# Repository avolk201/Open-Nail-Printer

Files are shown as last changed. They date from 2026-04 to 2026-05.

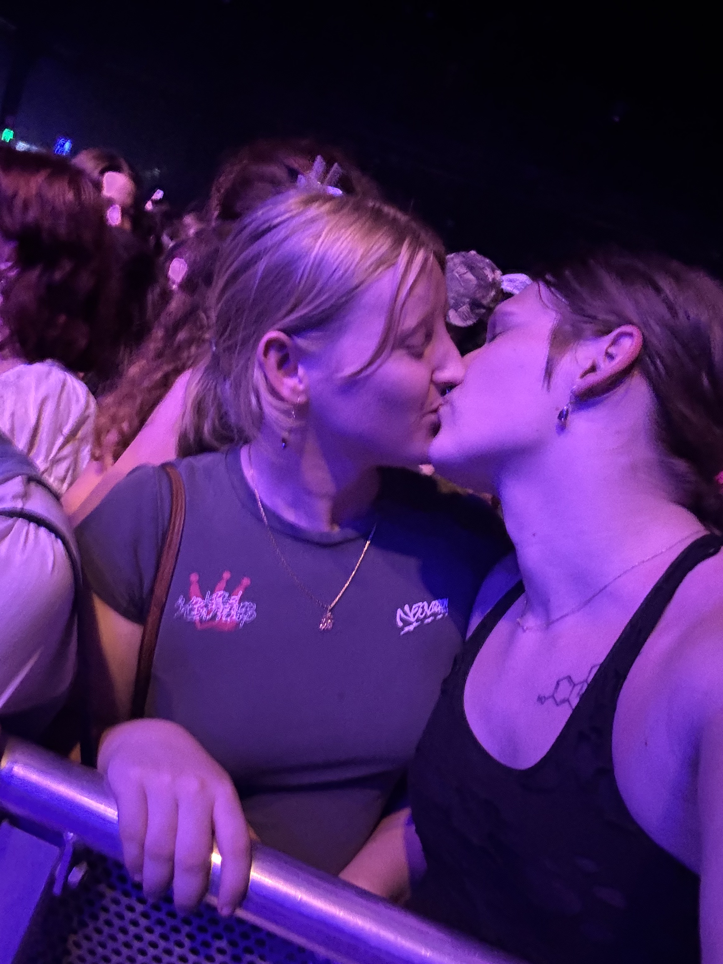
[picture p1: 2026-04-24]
backend/uploads/ethel cain.jpeg

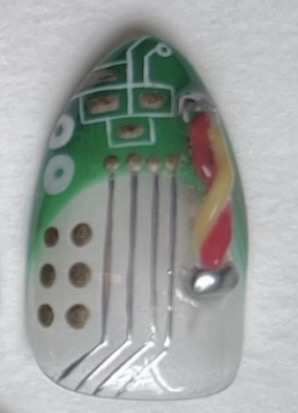
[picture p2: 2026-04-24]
backend/uploads/IMG_1966.jpeg

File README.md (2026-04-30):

# Open-Source Inkjet Nail Printer

## Overview
This repository contains the hardware schematics, firmware, and software required to build a custom, desktop-scale inkjet nail printer. The system utilizes a standard thermal inkjet (TIJ) cartridge (HP 63) to deposit water-based cosmetic/edible ink directly onto a prepared human nail. 

Unlike commercial alternatives that rely on closed-source hardware and DRM-locked consumables, this project provides a fully open architecture. It uses a distributed processing model, offloading high-level computer vision and web serving to a Raspberry Pi, while delegating strict, microsecond-accurate hardware control to an ESP32 microcontroller utilizing I2S Direct Memory Access (DMA).

## System Architecture

The project is divided into three distinct operational domains:

### 1. High-Level Processing (Raspberry Pi 3B+)
* **Environment:** Python 3, FastAPI, OpenCV.
* **Function:** Operates in a headless kiosk mode serving a React/Vue frontend to a local touchscreen UI. 
* **Vision Pipeline:** Captures the finger via a fixed-focus, low-distortion downward-facing camera. Allows the user to define a bounding box, warps the selected 2D image using a 1D sine-wave pre-distortion algorithm to map to the nail's curvature, and converts the RGB image into a binary CMYK halftone matrix via Floyd-Steinberg error diffusion.
* **Communication:** Slices the halftone matrix into 42-byte chunks and transmits them via UART over USB to the ESP32 at 921,600 baud.

### 2. Real-Time Hardware Control (ESP32)
* **Environment:** ESP-IDF (C), FreeRTOS.
* **Core 0:** Dedicated to receiving UART payloads and buffering them into FreeRTOS queues.
* **Core 1:** Manages electromechanical synchronization. Triggers the I2S DMA peripheral to output perfectly timed 5µs pulses across 12 parallel GPIO pins without CPU blocking. 
* **Motion Control:** Interfaces with TMC2209 stepper drivers for silent, vibration-free gantry movement, utilizing a linear optical encoder and hardware pulse counting (PCNT) for absolute microscopic positional accuracy.

### 3. Custom PCB & Power Distribution
The electrical architecture is split across two custom KiCad boards to ensure signal integrity and isolate high voltages:
* **Stationary Mainboard:** Houses the ESP32, TMC2209 drivers, and the central Power Distribution Network (PDN). It steps a 24V DC input down to 16V (Printhead), 9V (Logic Leveling), and 5V (Raspberry Pi/ESP32 supply).
* **Smart Carriage:** A lightweight, moving PCB connected via a Flexible Flat Cable (FFC). It houses CD4504B CMOS level shifters to step 3.3V data lines to 9V, and a custom P-Channel/N-Channel discrete MOSFET array to switch 16V firing pulses millimeters away from the cartridge's pogo-pin interface, eliminating inductive ringing.

## Safety & Hardware Interlocks
A critical feature of this design is the hardware "guillotine" failsafe located on the Smart Carriage. 

Thermal inkjet resistors will permanently burn out if held high for more than a few microseconds. To protect against software lockups, the 16V firing lines are routed through an AC-coupled gate drive (capacitive differentiator). An RC time-constant enforces a strict physical timeout of approximately 10-15µs. If the ESP32 freezes while a firing pin is pulled high, the capacitor will charge and autonomously sever the 16V supply to the cartridge, preventing thermal runaway.

## Repository Structure

* `/cad`: (In Progress) Onshape mechanical assemblies, STL files, and 3D printable carriage mounts.
* `/Nail-printer-embedded`: ESP-IDF C source code and FreeRTOS task configurations.
* `/NailPrinter_PCB`: KiCad 8.0 project files, library symbols, and footprints.
## Project Status

### Completed Features
* **Backend (Raspberry Pi)**
    * FastAPI server architecture with REST endpoints for system control and design management.
    * Computer Vision pipeline: Floyd-Steinberg halftoning (RGB to CMYK), 1D sine-wave nail warping, and manual affine transformations.
    * High-speed UART serial protocol (921,600 baud) for ESP32 communication.
    * MJPEG camera streaming for real-time nail alignment.
* **Frontend (Touchscreen UI)**
    * Vue 3/Vite application optimized for 7" Raspberry Pi touchscreen.
    * Interactive alignment interface with manual bounding box selection.
    * Real-time design adjustment (scale, rotation, pan) via overlay.
    * Design gallery and "Set" printing workflow for sequential multi-finger printing.
* **Firmware (ESP32)**
    * Dual-core task distribution: UART ingestion on Core 0, motion/sync on Core 1.
    * I2S Parallel DMA driver for microsecond-accurate HP 63 cartridge firing.
    * TMC2209 stepper driver integration via UART and MCPWM pulse generation.
    * Hardware pulse counting (PCNT) infrastructure for linear optical encoder feedback.
* **Hardware (KiCad)**
    * Two-board architecture: Stationary Mainboard and Smart Carriage.
    * Power distribution for 24V, 16V (firing), 9V (logic), and 5V (MCU) rails.
    * Hardware guillotine failsafe using capacitive AC-coupling.

### Pending / TODO
* **Firmware**
    * Implement hardware-level trigger linking PCNT encoder thresholds to I2S DMA output for closed-loop positional accuracy.
    * Complete homing sequence logic within limit switch ISR handlers.
    * Implement S-curve acceleration ramps for smoother gantry motion.
* **Backend**
    * Replace OpenCV camera capture with native `libcamera` or `picamera2` for Raspberry Pi hardware.
    * Implement automated nail segmentation to replace manual bounding box alignment.
* **Hardware**
    * Verify and resolve 9V/3.3V domain crossing alerts in schematic.
    * Add fiducial markers for automated pick-and-place assembly.
    * Populate manufacturer part numbers (MPNs) across the Bill of Materials.
* **Mechanics**
    * Finalize and release Onshape CAD assemblies and 3D printable STL files for the gantry and carriage.

## Development Milestones

1.  **Software**: Implementation of the FastAPI server, Vue UI, and CMYK halftoning pipeline. [DONE]
2.  **Hardware Design**: Design and layout of the Mainboard and Smart Carriage PCBs. [DONE]
3.  **Hardware Validation**: Manufacture PCBs and confirm functional operation. [TODO]
4.  **Firmware Core**: High-speed communication and raw I2S printhead driving. [DONE]
5.  **Motion Control Integration**: Synchronization of gantry movement with firmware step generation. [IN PROGRESS]
6.  **Closed-Loop Accuracy**: Linking linear optical encoder pulses to hardware-triggered ink deposition. [TODO]
7.  **Kiosk Mode Integration**: Final Raspberry Pi OS configuration for standalone touchscreen operation. [TODO]
8.  **System Validation**: Full 5-finger print test using water-based cosmetic ink. [TODO]

### Prerequisites
* Raspberry Pi OS Lite (64-bit)
* Espressif ESP-IDF v5.x
* KiCad 8.0+
* 24V 3A DC Power Supply
* Modified HP 63 Tri-Color Cartridge (Flushed and refilled with water-based cosmetic/edible ink).

### Software Setup
1. Clone the repository to the Raspberry Pi.
2. Navigate to `backend/` and install dependencies: `pip install -r requirements.txt`.
3. Configure the Pi to launch the FastAPI server on boot.
4. Flash the ESP32 firmware: `idf.py build flash monitor`.

## License
This project is licensed under the MIT License. See the `LICENSE` file for details. Note that any proprietary modifications to the HP 63 cartridge footprint are for educational and research purposes only.

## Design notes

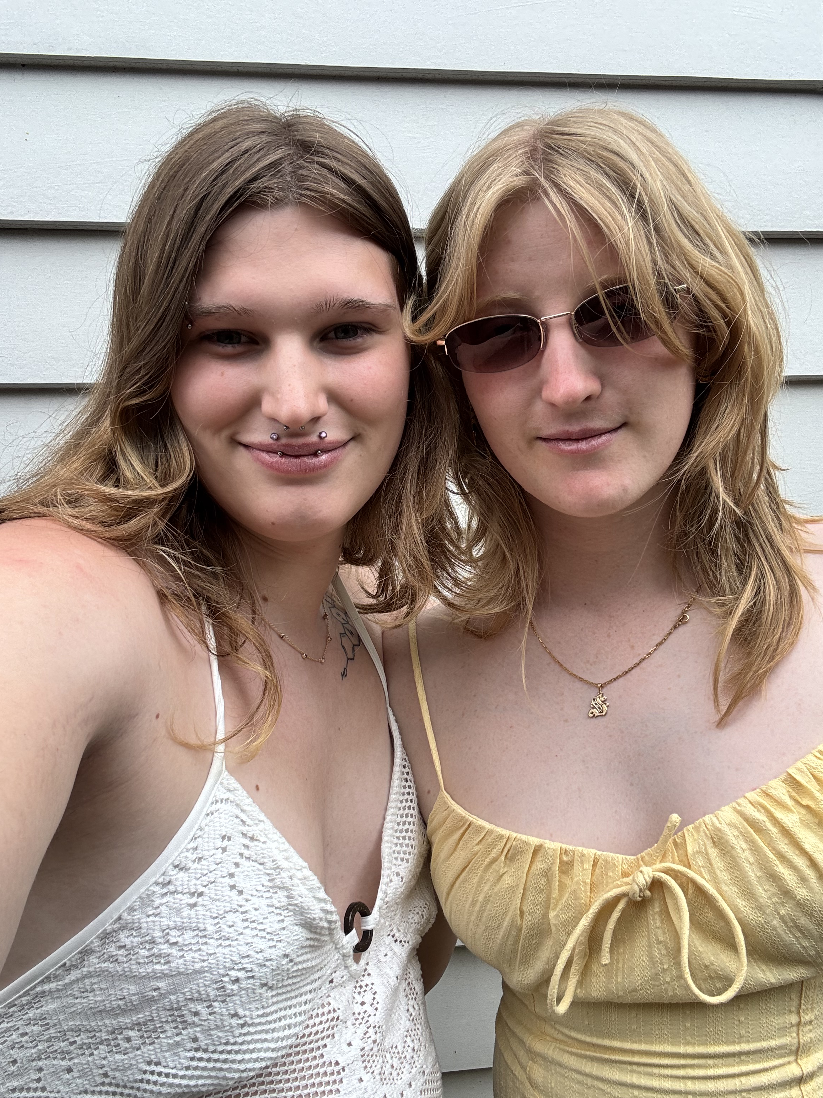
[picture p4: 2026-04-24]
backend/uploads/christmas.jpeg

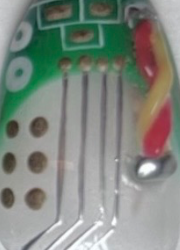
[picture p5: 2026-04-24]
backend/uploads/cropped_1777023158808.png

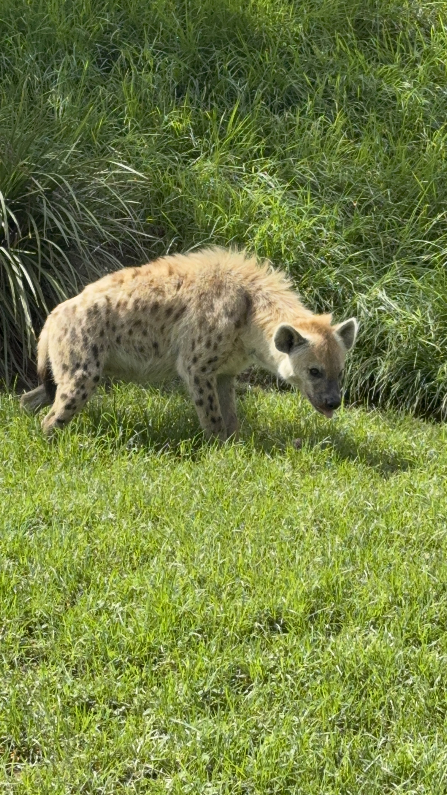
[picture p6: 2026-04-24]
backend/uploads/feeding atana.jpeg

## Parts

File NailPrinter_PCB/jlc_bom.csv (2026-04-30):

Comment | Designator | Footprint | LCSC Part #
100uF | C2,C1 | CP_Radial_D6.3mm_P2.50mm | C10850
10n | C4,C7,C3,C8 | 0805
100n | C5,C6 | 0805
100m | C9
Fuse | F1 | FuseHolder_Blade_ATO_Littelfuse_FLR_178.6165
Barrel_Jack | J1 | BarrelJack_Horizontal | C15178
Conn_01x03 | J2 | JST_XH_B3B-XH-AM_1x03_P2.50mm_Vertical
Conn_01x04 | J4,J8,J3,J6,J5 | JST_XH_B4B-XH-A_1x04_P2.50mm_Vertical
Conn_01x03 | J7 | JST_XH_B3B-XH-A_1x03_P2.50mm_Vertical
Conn_01x24 | J10,J9 | IDC-Header_2x12_P2.54mm_Vertical
AO3401 | Q1,Q2 | SOT-23
10k | R1,R5 | 0805
1k | R2,R7,R6,R3 | 0805
2.7 | R8,R4 | 0805
22 | R14,R11,R10,R18,R17,R13,R12,R9,R15,R16 |  | C3014177
SW_SPST | SW1 | PinHeader_1x03_P2.54mm_Vertical
DEVKIT_V1_ESP32-WROOM-32 | U1 | MODULE_DEVKIT_V1_ESP32-WROOM-32
AO3400 | U2,U5 | SOT-23
CD4504BM | U3,U4 | SOIC-16_3.9x9.9mm_P1.27mm | C151885

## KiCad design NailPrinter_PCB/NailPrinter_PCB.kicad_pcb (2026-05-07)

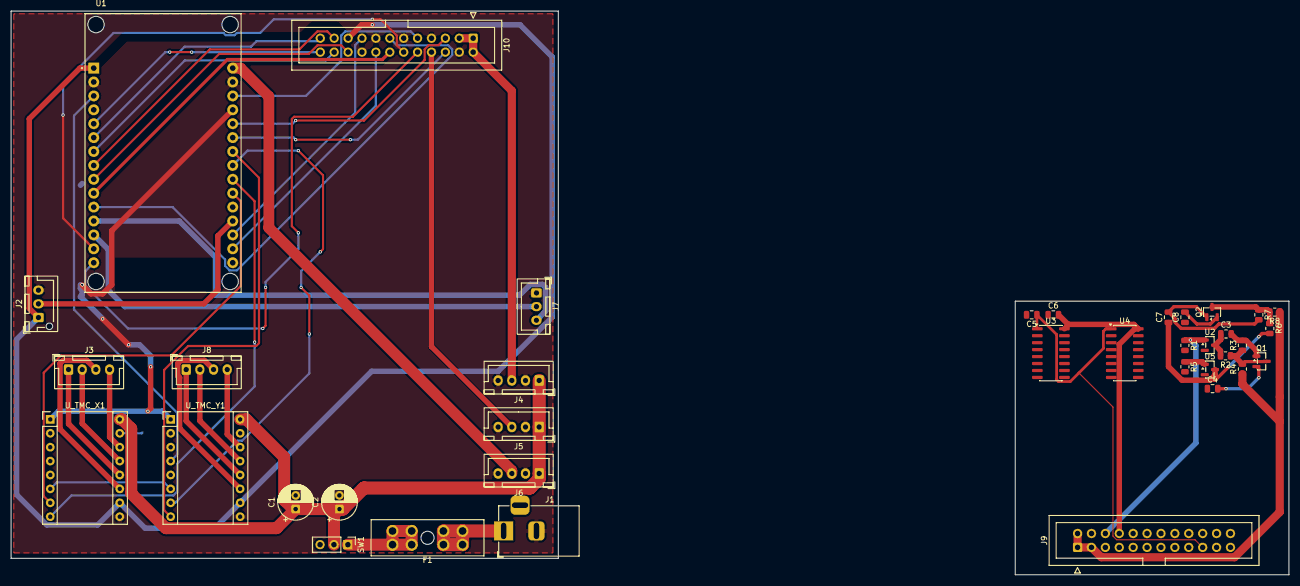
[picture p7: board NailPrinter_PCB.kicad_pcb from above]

Board: 2 copper layers, 233.5 x 103.0 mm, 37 parts (0 on the bottom side), 47 nets.

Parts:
C1, C2: 100uF; CP_Radial_D6.3mm_P2.50mm
C3, C4, C7, C8: 10n; C_0805_2012Metric
C5, C6: 100n; C_0805_2012Metric
F1: Fuse; FuseHolder_Blade_ATO_Littelfuse_FLR_178.6165
J1: Barrel_Jack; BarrelJack_Horizontal
J2: Conn_01x03; JST_XH_B3B-XH-AM_1x03_P2.50mm_Vertical
J3, J4, J5, J6, J8: Conn_01x04; JST_XH_B4B-XH-A_1x04_P2.50mm_Vertical
J7: Conn_01x03; JST_XH_B3B-XH-A_1x03_P2.50mm_Vertical
J9, J10: Conn_01x24; IDC-Header_2x12_P2.54mm_Vertical
Q1, Q2: AO3401; SOT-23
R1, R5: 10k; R_0805_2012Metric
R2, R3, R6, R7: 1k; R_0805_2012Metric
R4, R8: 2.7; R_0805_2012Metric
SW1: SW_SPST; PinHeader_1x03_P2.54mm_Vertical
U1: DEVKIT_V1_ESP32-WROOM-32; MODULE_DEVKIT_V1_ESP32-WROOM-32
U2, U5: AO3400; SOT-23
U3, U4: CD4504BM; SOIC-16_3.9x9.9mm_P1.27mm
U_TMC_X1: BTT_TMC2209_V1.2; Pololu_Breakout-16_15.2x20.3mm
U_TMC_Y1: BTT_TMC2209_V1.2; Pololu_Breakout-16_15.2x20.3mm

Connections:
+3.3V: C5.1, J2.1, J9.19, J10.19, U1.1 (3V3), U3.1 (VCC), U4.1 (VCC), U_TMC_X1.10 (VIO), U_TMC_Y1.10 (VIO)
+5V: J6.3, U1.30 (EXT_5V)
+9V: C6.2, J5.3, J9.8, J10.8, U3.16 (VDD), U4.16 (VDD)
+16V: J4.3, J9.1, J9.2, J9.3, J10.1, J10.2, J10.3, R4.1, R8.1
+24V: C1.1, C2.1, J4.1, J5.1, J6.1, SW1.2 (B), U_TMC_X1.16 (VM), U_TMC_Y1.16 (VM)
CLK_3V: J10.10, U1.15 (IO23), U3.7 (CIN)
D1_3V: J10.12, U1.14 (IO22), U3.11 (EIN)
D2_3V: J10.13, U1.11 (IO21), U3.5 (BIN)
D3_3V: J10.14, U1.10 (IO19), U3.9 (DIN)
D4_3V: J10.20, U1.9 (IO18), U3.14 (FIN)
D5_3V: J10.21, U1.8 (IO5), U4.3 (AIN)
D6_3V: J10.22, U1.7 (IO17), U4.5 (BIN)
D7_3V: J10.23, U1.6 (IO16), U4.7 (CIN)
D8_3V: J10.24, U1.5 (IO4), U4.9 (DIN)
DIR_X: U1.22 (IO33), U_TMC_X1.8 (DIR)
DIR_Y: U1.24 (IO26), U_TMC_Y1.8 (DIR)
ENC_A: J9.16, J10.16, U1.17 (SENSOR_VP)
ENC_B: J9.17, J10.17, U1.18 (SENSOR_VN)
ENDSTOP_X: J2.2, U1.19 (IO34)
EN_MOTORS: U1.27 (IO12), U_TMC_X1.1 (EN), U_TMC_Y1.1 (EN)
GND: C1.2, C2.2, C4.1, C5.2, C6.1, C8.1, J1.2, J2.3, J4.2, J4.4, J5.2, J5.4, J6.2, J6.4, J7.1, J9.4, J9.7, J9.11, J9.15, J9.18, J10.4, J10.7, J10.11, J10.15, J10.18, R1.2, R5.2, U1.2 (GND1), U1.29 (GND2), U2.2, U3.8 (VSS), U3.13 (SELECT), U4.8 (VSS), U4.11 (EIN), U4.13 (SELECT), U4.14 (FIN), U5.2, U_TMC_X1.9 (GND), U_TMC_X1.15 (GND), U_TMC_Y1.9 (GND), U_TMC_Y1.15 (GND)
unnamed: C3.1, R2.2, U2.3
unnamed: C3.2, Q1.1, R3.2
unnamed: C7.1, R6.2, U5.3
unnamed: C7.2, Q2.1, R7.2
unnamed: F1.1, J1.1
unnamed: J3.1, U_TMC_X1.12 (OA1)
unnamed: J3.2, U_TMC_X1.13 (OA2)
unnamed: J3.3, U_TMC_X1.11 (OB1)
unnamed: J3.4, U_TMC_X1.14 (OB2)
unnamed: J7.2, U1.13 (TXD0)
unnamed: J7.3, U1.12 (RXD0)
unnamed: J8.1, U_TMC_Y1.12 (OA1)
unnamed: J8.2, U_TMC_Y1.13 (OA2)
unnamed: J8.3, U_TMC_Y1.11 (OB1)
unnamed: J8.4, U_TMC_Y1.14 (OB2)
unnamed: Q1.3, R2.1, R3.1, R4.2
unnamed: Q2.3, R6.1, R7.1, R8.2
unnamed: F1.2, SW1.1 (A)
PWRA_IN: J9.6, J10.6, R1.1, U1.25 (IO27), U2.1
PWRA_OUT: C4.2, Q1.2
PWRB_IN: J9.5, J10.5, R5.1, U1.26 (IO14), U5.1
PWRB_OUT: C8.2, Q2.2
STEP_X: U1.21 (IO32), U_TMC_X1.7 (STEP)
STEP_Y: U1.23 (IO25), U_TMC_Y1.7 (STEP)
SYNC_3V: J10.9, U1.28 (IO13), U3.3 (AIN)
UART_Y: U1.3 (IO15), U_TMC_Y1.4 (PDN/UART1)

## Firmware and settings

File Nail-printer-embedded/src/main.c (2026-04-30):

#include <stdio.h>
#include <string.h>
#include "freertos/FreeRTOS.h"
#include "freertos/task.h"
#include "freertos/queue.h"
#include "freertos/ringbuf.h"
#include "driver/uart.h"
#include "driver/gpio.h"
#include "driver/pulse_cnt.h"
#include "driver/mcpwm_prelude.h"
#include "printcart_buffer_filler.h"
#include "printcart_genwaveform.h"
#include "printcart_i2s.h"

// Define cartridge type
#define CART_IS_COLOR 1

// GPIO numbers for the lines that are connected to the printer cartridge.
#define PIN_NUM_CART_D1 22
#define PIN_NUM_CART_D2 21
#define PIN_NUM_CART_D3 19
#define PIN_NUM_CART_CSYNC 13
#define PIN_NUM_CART_S1 18
#define PIN_NUM_CART_S2 5
#define PIN_NUM_CART_S3 17
#define PIN_NUM_CART_S4 16
#define PIN_NUM_CART_S5 4
#define PIN_NUM_CART_DCLK 23
#define PIN_NUM_CART_F3 27
#define PIN_NUM_CART_F5 14

// UART Configuration for RPi communication via USB/Serial
#define UART_NUM UART_NUM_0
#define BUF_SIZE (4096) // Increased for robust ringbuffer ingestion

// UART Configuration for TMC2209
#define TMC_UART_NUM UART_NUM_1
#define TMC_TX_PIN 15
#define TMC_RX_PIN 15 // Single-wire UART shared

// Encoder Pins
#define ENCODER_PIN_A 36
#define ENCODER_PIN_B 39

// Limit Switch Pins
#define LIMIT_X_PIN 34
#define LIMIT_Y_PIN 35

// Stepper Motor Pins
#define MOTOR_X_STEP_PIN 32
#define MOTOR_X_DIR_PIN  33
#define MOTOR_Y_STEP_PIN 25
#define MOTOR_Y_DIR_PIN  26
#define MOTOR_Z_STEP_PIN -1 // Not used in this hardware
#define MOTOR_Z_DIR_PIN  -1
#define MOTOR_ENABLE_PIN 12

// Protocol constants
#define CMD_START_PRINT 0x01
#define CMD_READY       0x02
#define CMD_SEND_LINE   0x03
#define CMD_LINE_ACK    0x04
#define CMD_HOME        0x05
#define CMD_LINE_NACK   0x06

#define WAVEFORM_DMALEN 1500

typedef struct {
    int target_x;
    int target_y;
    int target_z;
    uint32_t speed_hz;
} motion_cmd_t;

QueueHandle_t nozdata_queue;
RingbufHandle_t uart_rx_ringbuf;
QueueHandle_t motion_queue;

mcpwm_timer_handle_t x_timer = NULL;
mcpwm_oper_handle_t x_oper = NULL;
mcpwm_cmpr_handle_t x_cmpr = NULL;
mcpwm_gen_handle_t x_gen = NULL;

// Interrupt Service Routine for Limit Switches
static void IRAM_ATTR limit_switch_isr_handler(void* arg) {
    uint32_t gpio_num = (uint32_t) arg;
    // Handle homing sequence interrupt
}

void tmc2209_init() {
    // TMC2209 Interfacing: UART configuration for stealthChop, microstepping, and motor current.
    uart_config_t tmc_uart_config = {
        .baud_rate = 115200,
        .data_bits = UART_DATA_8_BITS,
        .parity = UART_PARITY_DISABLE,
        .stop_bits = UART_STOP_BITS_1,
        .flow_ctrl = UART_HW_FLOWCTRL_DISABLE,
        .source_clk = UART_SCLK_APB,
    };
    uart_param_config(TMC_UART_NUM, &tmc_uart_config);
    uart_set_pin(TMC_UART_NUM, TMC_TX_PIN, TMC_RX_PIN, UART_PIN_NO_CHANGE, UART_PIN_NO_CHANGE);
    uart_driver_install(TMC_UART_NUM, 1024, 0, 0, NULL, 0);
    printf("TMC2209 UART initialized\n");
    
    // Set parameters over UART (Pseudo-code for TMC2209 setup)
    // tmc2209_write_reg(TMC_UART_NUM, TMC2209_REG_GCONF, 0x00000008); // Enable stealthChop
    // tmc2209_write_reg(TMC_UART_NUM, TMC2209_REG_IHOLD_IRUN, 0x000F1008); // Set motor currents
}

void motion_init() {
    // Step/Dir Generation: ESP32 MCPWM peripheral for smooth acceleration/deceleration.
    printf("Initializing Motion Control MCPWM...\n");
    
    motion_queue = xQueueCreate(10, sizeof(motion_cmd_t));

    // Setup DIR and ENABLE pins
    gpio_config_t dir_conf = {
        .intr_type = GPIO_INTR_DISABLE,
        .mode = GPIO_MODE_OUTPUT,
        .pin_bit_mask = (1ULL<<MOTOR_X_DIR_PIN) | (1ULL<<MOTOR_Y_DIR_PIN) | (1ULL<<MOTOR_ENABLE_PIN),
        .pull_down_en = 0,
        .pull_up_en = 0
    };
    gpio_config(&dir_conf);
    gpio_set_level(MOTOR_ENABLE_PIN, 0); // Enable drivers (typically active low)

    // X-Axis MCPWM timer for generating Step Pulses
    mcpwm_timer_config_t timer_config = {
        .group_id = 0,
        .clk_src = MCPWM_TIMER_CLK_SRC_DEFAULT,
        .resolution_hz = 1000000, // 1MHz, 1us per tick
        .period_ticks = 1000,     // Initial 1kHz step rate
        .count_mode = MCPWM_TIMER_COUNT_MODE_UP,
    };
    mcpwm_new_timer(&timer_config, &x_timer);

    mcpwm_operator_config_t oper_config = {
        .group_id = 0, // same as timer
    };
    mcpwm_new_operator(&oper_config, &x_oper);
    mcpwm_operator_connect_timer(x_oper, x_timer);

    mcpwm_comparator_config_t cmpr_config = {
        .flags.update_cmp_on_tez = true,
    };
    mcpwm_new_comparator(x_oper, &cmpr_config, &x_cmpr);
    
    // Set 50% duty cycle initially
    mcpwm_comparator_set_compare_value(x_cmpr, 500); 

    mcpwm_generator_config_t gen_config = {
        .gen_gpio_num = MOTOR_X_STEP_PIN,
    };
    mcpwm_new_generator(x_oper, &gen_config, &x_gen);

    // Generator actions: go high at timer zero, go low at compare match (50% duty pulse)
    mcpwm_generator_set_action_on_timer_event(x_gen, 
        MCPWM_GEN_TIMER_EVENT_ACTION(MCPWM_TIMER_DIRECTION_UP, MCPWM_TIMER_EVENT_EMPTY, MCPWM_GEN_ACTION_HIGH));
    mcpwm_generator_set_action_on_compare_event(x_gen, 
        MCPWM_GEN_COMPARE_EVENT_ACTION(MCPWM_TIMER_DIRECTION_UP, x_cmpr, MCPWM_GEN_ACTION_LOW));

    mcpwm_timer_enable(x_timer);
    
    printf("Motion Control MCPWM initialized for X-Axis\n");
}

void homing_init() {
    // Homing Sequence: Limit switch interrupts prior to printing.
    gpio_config_t io_conf = {
        .intr_type = GPIO_INTR_NEGEDGE,
        .pin_bit_mask = (1ULL << LIMIT_X_PIN) | (1ULL << LIMIT_Y_PIN),
        .mode = GPIO_MODE_INPUT,
        .pull_up_en = 1,
    };
    gpio_config(&io_conf);
    
    gpio_install_isr_service(0);
    gpio_isr_handler_add(LIMIT_X_PIN, limit_switch_isr_handler, (void*) LIMIT_X_PIN);
    gpio_isr_handler_add(LIMIT_Y_PIN, limit_switch_isr_handler, (void*) LIMIT_Y_PIN);
    printf("Homing interrupts initialized\n");
}

void pcnt_encoder_init() {
    // Absolute Positioning (PCNT): Configure ESP32 PCNT to read 150 LPI optical encoder.
    pcnt_unit_config_t unit_config = {
        .high_limit = 10000,
        .low_limit = -10000,
    };
    pcnt_unit_handle_t pcnt_unit = NULL;
    pcnt_new_unit(&unit_config, &pcnt_unit);

    pcnt_glitch_filter_config_t filter_config = {
        .max_glitch_ns = 1000,
    };
    pcnt_unit_set_glitch_filter(pcnt_unit, &filter_config);

    pcnt_chan_config_t chan_a_config = {
        .edge_gpio_num = ENCODER_PIN_A,
        .level_gpio_num = ENCODER_PIN_B,
    };
    pcnt_channel_handle_t pcnt_chan_a = NULL;
    pcnt_new_channel(pcnt_unit, &chan_a_config, &pcnt_chan_a);

    pcnt_channel_set_edge_action(pcnt_chan_a, PCNT_CHANNEL_EDGE_ACTION_DECREASE, PCNT_CHANNEL_EDGE_ACTION_INCREASE);
    pcnt_channel_set_level_action(pcnt_chan_a, PCNT_CHANNEL_LEVEL_ACTION_KEEP, PCNT_CHANNEL_LEVEL_ACTION_INVERSE);

    pcnt_unit_enable(pcnt_unit);
    pcnt_unit_clear_count(pcnt_unit);
    pcnt_unit_start(pcnt_unit);
    
    // TODO: Create a watchpoint interrupt or hardware trigger that links PCNT threshold to I2S DMA output.
    printf("PCNT Encoder initialized\n");
}

void printcart_init() {
    // Create nozzle data queue
    nozdata_queue = xQueueCreate(10, PRINTCART_NOZDATA_SZ);
    
    // Initialize I2S DMA across 12 GPIO pins simultaneously.
    i2s_parallel_config_t i2scfg = {
        .gpio_bus = {
            PIN_NUM_CART_D1, //0
            PIN_NUM_CART_D2, //1
            PIN_NUM_CART_D3, //2
            PIN_NUM_CART_CSYNC, //3
            PIN_NUM_CART_S2, //4
            PIN_NUM_CART_S4, //5
            PIN_NUM_CART_S1, //6
            PIN_NUM_CART_S5, //7
            PIN_NUM_CART_DCLK, //8
            PIN_NUM_CART_S3, //9
            PIN_NUM_CART_F3, //10
            PIN_NUM_CART_F5, //11
            -1, -1, -1, -1 //12-15 - unused
        },
        .bits = I2S_PARALLEL_BITS_16,
        .clkspeed_hz = 3333333, //3.3MHz
        .bufsz = WAVEFORM_DMALEN * sizeof(uint16_t),
        .refill_cb = printcart_buffer_filler_fn,
        .refill_cb_arg = nozdata_queue
    };
    // Ensure the DMA descriptors are tightly synchronized with the encoder pulses
    // so ink is deposited exactly on the grid, regardless of gantry speed fluctuations.
    i2s_parallel_setup(&I2S1, &i2scfg);
    i2s_parallel_start(&I2S1);
    
#ifdef CART_IS_COLOR
    printcart_select_waveform(PRINTCART_WAVEFORM_COLOR_B);
#endif

    printf("Printcart driver inited (I2S Parallel)\n");
}

void uart_init() {
    // Robust ringbuffer is handled by the ESP-IDF UART driver internally when sizing > 0
    uart_config_t uart_config = {
        .baud_rate = 921600,
        .data_bits = UART_DATA_8_BITS,
        .parity    = UART_PARITY_DISABLE,
        .stop_bits = UART_STOP_BITS_1,
        .flow_ctrl = UART_HW_FLOWCTRL_DISABLE,
        .source_clk = UART_SCLK_APB,
    };
    // Using UART0 which is typically the default serial connected via USB to RPi
    uart_param_config(UART_NUM, &uart_config);
    uart_set_pin(UART_NUM, UART_PIN_NO_CHANGE, UART_PIN_NO_CHANGE, UART_PIN_NO_CHANGE, UART_PIN_NO_CHANGE);
    // Large RX buffer to ingest 921,600 baud data without dropping frames
    uart_driver_install(UART_NUM, BUF_SIZE, 0, 0, NULL, 0); 
    
    // Also create a FreeRTOS ringbuffer if we need to manually queue items further
    uart_rx_ringbuf = xRingbufferCreate(BUF_SIZE, RINGBUF_TYPE_BYTEBUF);
    
    printf("UART communication with Open-Nail-Printer initialized\n");
}

void uart_rx_task(void *arg) {
    uint8_t rx_byte;
    uint8_t line_buffer[PRINTCART_NOZDATA_SZ];
    
    while (1) {
        int len = uart_read_bytes(UART_NUM, &rx_byte, 1, portMAX_DELAY);
        if (len > 0) {
            switch (rx_byte) {
                case CMD_START_PRINT: {
                    xQueueReset(nozdata_queue);
                    uint8_t tx = CMD_READY;
                    uart_write_bytes(UART_NUM, (const char*)&tx, 1);
                    break;
                }
                case CMD_SEND_LINE: {
                    // Wait for exactly PRINTCART_NOZDATA_SZ bytes
                    int bytes_read = 0;
                    while (bytes_read < PRINTCART_NOZDATA_SZ) {
                        int r = uart_read_bytes(UART_NUM, line_buffer + bytes_read, PRINTCART_NOZDATA_SZ - bytes_read, pdMS_TO_TICKS(100));
                        if (r > 0) {
                            bytes_read += r;
                        } else {
                            break; // timeout
                        }
                    }
                    if (bytes_read == PRINTCART_NOZDATA_SZ) {
                        // Queue the data for I2S output to Cartridge
                        // Don't block forever, if queue full send NACK
                        if (xQueueSend(nozdata_queue, line_buffer, pdMS_TO_TICKS(10)) == pdTRUE) {
                            // Send ACK
                            uint8_t tx = CMD_LINE_ACK;
                            uart_write_bytes(UART_NUM, (const char*)&tx, 1);
                        } else {
                            // Queue full, send NACK
                            uint8_t tx = CMD_LINE_NACK;
                            uart_write_bytes(UART_NUM, (const char*)&tx, 1);
                        }
                    } else {
                        // Timeout reading, send NACK
                        uint8_t tx = CMD_LINE_NACK;
                        uart_write_bytes(UART_NUM, (const char*)&tx, 1);
                    }
                    break;
                }
                case CMD_HOME: {
                    // Implement homing if applicable
                    uint8_t tx = CMD_READY;
                    uart_write_bytes(UART_NUM, (const char*)&tx, 1);
                    break;
                }
            }
        }
    }
}

void motion_control_task(void *arg) {
    // This task handles Gantry Implementation & Motion Control
    motion_cmd_t cmd;
    while (1) {
        if (xQueueReceive(motion_queue, &cmd, portMAX_DELAY) == pdTRUE) {
            // Process motion command
            // 1. Set Directions
            gpio_set_level(MOTOR_X_DIR_PIN, cmd.target_x > 0 ? 1 : 0);
            gpio_set_level(MOTOR_Y_DIR_PIN, cmd.target_y > 0 ? 1 : 0);
            
            // 2. Configure speed (simplified, assuming X is primary axis)
            if (cmd.speed_hz > 0) {
                // Generate steps using MCPWM
                mcpwm_timer_start_stop(x_timer, MCPWM_TIMER_START_NO_STOP);
                
                // Placeholder: Wait for encoder/steps to reach target
                // In a full implementation, the PCNT would trigger a stop or interrupt.
                vTaskDelay(pdMS_TO_TICKS(100)); 
                
                // 3. Stop motion
                mcpwm_timer_start_stop(x_timer, MCPWM_TIMER_STOP_EMPTY);
            }
        }
    }
}

void printhead_sync_task(void *arg) {
    // This task monitors the PCNT thresholds and links them to the I2S DMA output
    while (1) {
        // Implement tight synchronization with encoder pulses
        vTaskDelay(pdMS_TO_TICKS(5));
    }
}

void app_main(void) {
    // Hardware setup
    uart_init();
    printcart_init();
    tmc2209_init();
    motion_init();
    homing_init();
    pcnt_encoder_init();
    
    // Dual-Core Task Pinning
    
    // Core 0: Pin the UART receiving task to Core 0 to ingest the 921,600 baud data.
    xTaskCreatePinnedToCore(uart_rx_task, "uart_rx_task", 4096, NULL, 10, NULL, 0);
    
    // Core 1: Pin the Motion Control and Printhead Sync tasks to Core 1.
    xTaskCreatePinnedToCore(motion_control_task, "motion_control_task", 4096, NULL, 9, NULL, 1);
    xTaskCreatePinnedToCore(printhead_sync_task, "printhead_sync_task", 4096, NULL, 10, NULL, 1);
}

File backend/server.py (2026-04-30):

import asyncio
import logging
import cv2
import numpy as np
import time
import json
import socket
import threading
from fastapi import FastAPI, UploadFile, File, HTTPException
from pydantic import BaseModel
from fastapi.staticfiles import StaticFiles
from fastapi.middleware.cors import CORSMiddleware
from fastapi.responses import JSONResponse, StreamingResponse, FileResponse
from typing import Optional
import os

class BBox(BaseModel):
    x: int
    y: int
    w: int
    h: int

class TransformParams(BaseModel):
    scale: float = 1.0
    rotation: float = 0.0
    x_offset: float = 0.0
    y_offset: float = 0.0

class PrintOptions(BaseModel):
    file_path: str = None
    transform: TransformParams = None

class SelectDesignRequest(BaseModel):
    type: str = "single"
    filename: Optional[str] = None
    set_data: Optional[dict] = None

class SetFingers(BaseModel):
    Thumb: str
    Index: str
    Middle: str
    Ring: str
    Pinky: str

class DesignSet(BaseModel):
    name: str
    fingers: SetFingers

from upload_handler import save_upload_file
from serial_comm import SerialManager
from cv_pipeline import run_pipeline

logging.basicConfig(level=logging.INFO)
logger = logging.getLogger(__name__)

app = FastAPI(title="Nail Printer Backend")

# Allow CORS for local development
app.add_middleware(
    CORSMiddleware,
    allow_origins=["*"],
    allow_credentials=True,
    allow_methods=["*"],
    allow_headers=["*"],
)

serial_manager = SerialManager(mock=True)

class CameraManager:
    def __init__(self):
        self.cap = None
        self.lock = threading.Lock()

    def get_frame(self):
        with self.lock:
            if self.cap is None or not self.cap.isOpened():
                # Index 1 is usually the external/Continuity camera on Mac
                self.cap = cv2.VideoCapture(2)
                time.sleep(0.5) # warmup
            success, frame = self.cap.read()
            if not success:
                return None
            return frame

    def release(self):
        if self.cap is not None:
            self.cap.release()
            self.cap = None

camera_manager = CameraManager()

# Global state
app.state.last_uploaded_file = None
app.state.last_alignment = None
app.state.active_type = "single"
app.state.active_set = None

SETS_FILE = "sets.json"

def load_sets():
    if os.path.exists(SETS_FILE):
        with open(SETS_FILE, 'r') as f:
            return json.load(f)
    return []

def save_sets(sets_data):
    with open(SETS_FILE, 'w') as f:
        json.dump(sets_data, f)

def get_local_ip():
    s = socket.socket(socket.AF_INET, socket.SOCK_DGRAM)
    try:
        s.connect(('10.255.255.255', 1))
        IP = s.getsockname()[0]
    except Exception:
        IP = '127.0.0.1'
    finally:
        s.close()
    return IP

@app.get("/api/system/ip")
async def get_ip():
    return {"ip": get_local_ip()}

@app.post("/api/upload")
async def upload_image(file: UploadFile = File(...)):
    if not file.content_type.startswith('image/'):
        raise HTTPException(status_code=400, detail="File must be an image.")
    
    file_path = await save_upload_file(file)
    app.state.last_uploaded_file = file_path
    logger.info(f"Image saved to {file_path}")
    return JSONResponse(content={"message": "Upload successful", "file_path": file_path})

@app.get("/api/design")
async def get_latest_design():
    if app.state.last_uploaded_file and os.path.exists(app.state.last_uploaded_file):
        return FileResponse(app.state.last_uploaded_file)
    else:
        raise HTTPException(status_code=404, detail="No design uploaded yet")

@app.get("/api/designs")
async def list_designs():
    upload_dir = "uploads"
    if not os.path.exists(upload_dir):
        return []
    files = [f for f in os.listdir(upload_dir) if os.path.isfile(os.path.join(upload_dir, f))]
    # Return newest first
    files.sort(key=lambda x: os.path.getmtime(os.path.join(upload_dir, x)), reverse=True)
    return [{"filename": f, "url": f"/uploads/{f}"} for f in files if f.lower().endswith(('.png', '.jpg', '.jpeg'))]

@app.post("/api/designs/select")
async def select_design(req: SelectDesignRequest):
    if req.type == "single":
        if not req.filename:
            raise HTTPException(status_code=400, detail="Filename required")
        file_path = os.path.join("uploads", req.filename)
        if not os.path.exists(file_path):
            raise HTTPException(status_code=404, detail="File not found")
        app.state.last_uploaded_file = file_path
        app.state.active_type = "single"
        app.state.active_set = None
        logger.info(f"Active single design set to {file_path}")
    elif req.type == "set":
        if not req.set_data:
            raise HTTPException(status_code=400, detail="Set data required")
        app.state.active_type = "set"
        app.state.active_set = req.set_data
        # Initialize first finger? We don't need to track current finger on backend, frontend does that.
        logger.info(f"Active design set configured to: {req.set_data['name']}")
    return {"message": "Design selected"}

@app.get("/api/designs/active")
async def get_active_design():
    if app.state.active_type == "single":
        filename = os.path.basename(app.state.last_uploaded_file) if app.state.last_uploaded_file else None
        return {"type": "single", "filename": filename, "url": f"/uploads/{filename}" if filename else None}
    else:
        return {"type": "set", "set": app.state.active_set}

@app.get("/api/sets")
async def get_sets():
    return load_sets()

@app.post("/api/sets")
async def create_set(design_set: DesignSet):
    sets = load_sets()
    new_set = design_set.dict()
    sets.insert(0, new_set) # Add to beginning
    save_sets(sets)
    return {"message": "Set saved successfully"}

def gen_frames():
    while True:
        frame = camera_manager.get_frame()
        if frame is not None:
            ret, buffer = cv2.imencode('.jpg', frame)
            frame_bytes = buffer.tobytes()
            yield (b'--frame\r\n'
                   b'Content-Type: image/jpeg\r\n\r\n' + frame_bytes + b'\r\n')
        time.sleep(0.05)

@app.get("/api/stream")
def video_stream():
    return StreamingResponse(gen_frames(), media_type="multipart/x-mixed-replace; boundary=frame")

@app.post("/api/home")
async def home_printer():
    logger.info("Homing printer requested.")
    await serial_manager.home()
    return {"message": "Homing sequence started"}

@app.post("/api/align")
async def align_printer(bbox: BBox):
    logger.info(f"Manual align requested with bbox: {bbox}")
    app.state.last_alignment = bbox.dict()
    return {"message": "Alignment coordinates saved successfully", "bbox": bbox.dict()}
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

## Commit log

2026-04-24 edited the server scripts and began pcb design
    [NailPrinter_PCB.kicad_pcb, NailPrinter_PCB.kicad_sch]
2026-04-25 added embedded c code (based on https://github.com/Spritetm/printercart_simple/tree/master)
2026-04-25 Beginning PCB Design and ReadMe
    [NailPrinter_PCB.kicad_sch, Smart_Carriage.kicad_sch, Stationary_Mainboard.kicad_sch]
2026-04-26 mostly schematic and pcb design
    [NailPrinter_PCB.kicad_pcb, Smart_Carriage.kicad_sch, Stationary_Mainboard.kicad_sch]
2026-04-26 Placed components on pcb
    [NailPrinter_PCB.kicad_pcb]
2026-04-26 Preliminary traces, probably needs a lot more tweaking
    [NailPrinter_PCB.kicad_pcb]
2026-04-30 Added TODO list to readme. Routed Mainboard PCB
    [NailPrinter_PCB.kicad_pcb, Stationary_Mainboard.kicad_sch, jlc_bom.csv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]
2026-05-07 Adjusting traces for the sake of signal integrity
    [NailPrinter_PCB.kicad_pcb]
